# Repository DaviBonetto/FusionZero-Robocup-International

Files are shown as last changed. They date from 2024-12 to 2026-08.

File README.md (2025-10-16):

# FusionZero: ROBOCUP INTERNATIONAL
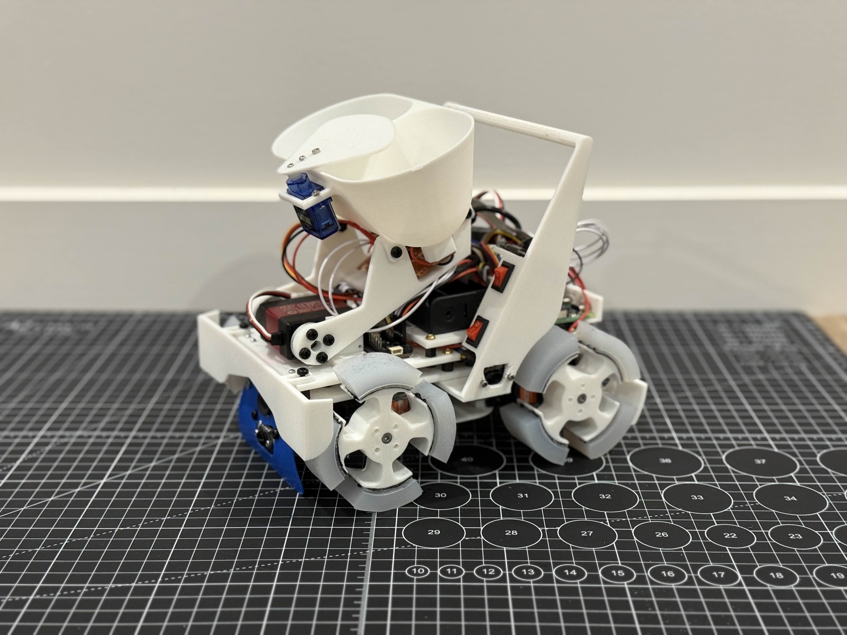
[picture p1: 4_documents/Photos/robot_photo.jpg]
Bot Photo


This is a continuation of our progress, following:
- Robocup Singapore Open 2024
- Robocup Australia Open 2024

This repository tracks progress through:
- Robocup Japan Open 2025
- Robocup Singapore Open 2025
- Robocup International, Salvador, Brazil 2025
- Robocup Australia International 2025

We recently placed 1st in Robocup Australia 2025, against previous champion, Catbot Jet. This repository will no longer be updated. A new one will be made for the 2026 international season. 

# Bill of Parts
## Computing
- [1] | Raspberry Pi 4B 4GB
- [1] | 32GB SD card

### Raspberry Pi Zero 2W Shield [CUSTOM]
- [2] | Toggle switches
- [1] | PCA8685 Chip
- [1] | 1000uF Capacitor
- [1] | 0.1uF Capacitor
- [4] | 5 Pin XH connectors female
- [2] | 4 Pin XH connectors female
- [4] | 2 Pin XH connectors female
- [1] | MOSFET

## Movement
- [4] | PDI 6221MG 360 (20, 360 degree, continuous)
- [1] | DSSERVO RDS3218 (20, 270 degree 20kg)

## Sensors
- [1] | ADS7830
- [1] | GY-BNOO85 9 Axis Accelerometer, Gyroscope, Magnetometer
- [2] | Limit switches
- [1] | Raspberry Pi Camera Module 3 Wide
- [1] | USB Camera

### IR Sensor Board [CUSTOM]
- [8] | TCRT5000
- [2] | Photoresistor
- [9] | 200kΩ Trimpot
- [5] | 1kΩTrimpot
- [4] | RGB LED

## Hardware
- [2] | 18650 Battery 
- [1] | LM2596 DC-DC buck converter 
- [1] | MINI560 Pro DC-DC converter
- [1] | 0.98" OLED Display

@BlanketOmelette
@D-uality

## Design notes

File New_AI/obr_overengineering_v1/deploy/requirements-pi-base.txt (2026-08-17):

psutil>=5.9,<7
pyserial==3.5
Pillow>=10,<11
adafruit-blinka>=8,<10
adafruit-circuitpython-pca9685>=3,<4

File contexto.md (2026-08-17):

Contexto comum para todos os agentes:

- Objetivo final: evoluir o pipeline oficial FusionZero OBR em `New_AI/obr_overengineering_v1` para um estado pronto para integração robusta com Raspberry Pi 3, dashboard remoto no PC e robô real, incluindo as 12 melhorias priorizadas.
- Entregavel final esperado: codigo implementado, testes, documentacao operacional, scripts de install/run, integracao consolidada e verificacao final sem regressao do pipeline oficial.
- Restricoes:
  - preservar o pipeline oficial atual
  - nao regredir `GREEN` vs `GREEN CORNER`
  - nao perder suporte a multiplas `SILVER`
  - `BLACK` nao pode voltar a virar linha
  - `Force LINE` e `Force RESCUE` devem continuar funcionando
  - manter dashboard remoto no PC e IA headless no Raspberry
  - nesta rodada nao executar deploy final no Raspberry; preparar e validar localmente
  - mudar somente o necessario com justificativa tecnica clara
- Criterio de sucesso:
  - as 12 melhorias implementadas ou preparadas de forma completa dentro da arquitetura oficials
  - testes relevantes passando
  - docs coerentes com o codigo
  - integracao clara e sem gaps
- Regra de comunicacao: reportar progresso em blocos curtos e listar bloqueios explicitamente.
- Regra de handoff: ao concluir, enviar output estruturado para o agente integrador, exceto o integrador que envia ao verificador final.

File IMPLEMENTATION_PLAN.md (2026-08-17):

# Plano de Implementação Técnico: IA e Interface - Robótica OBR (Resgate)

Este é um plano estratégico, modular e focado em engenharia de sistemas embarcados para migrar a arquitetura base atual (`pc_vision_ui.py` / `pc_vision_runner.py`) do repositório FusionZero-Robocup-International para uma arquitetura avançada de alto desempenho inspirada na equipe _Over Engineering_.

---

## 🔬 1. Diagnóstico Inicial

### Arquitetura Atual

- **UI & Core acoplados:** A interface visual está acoplada fisicamente às threads de atualização da captura, tornando o sistema engessado e de difícil expansão para renderização mais complexa (como gráficos 3D ou histórico de mapa dinâmico).
- **Sobrecarga de Detecção:** A visão computacional pesquisa elementos de forma generalizada. Para aplicações reais em Raspberry Pi/Hardware Embarcado, buscar todos os objetos a todo frame sem filtro de contexto do estado atual do robô causa latência inaceitável e falsos positivos.
- **Detecção do Vermelho Simplista:** A tolerância luminosa costuma falhar sob os holofotes do campeonato, considerando que a máscara HSV vermelha muitas vezes captura espectros vizinhos de laranja ou ignora bordas.
- **Estado Implícito:** A falta de uma Máquina de Estados Finita (FSM) rigorosa gera mensagens dessincronizadas do robô.

### Arquitetura Proposta

- **Message Broker Interno (Event Bus):** Usar ZeroMQ, Pub/Sub, ou filas do Python (`queue.Queue`/`asyncio`) para isolar Visão, Navegação e Interface.
- **Context-Aware Vision:** Pipeline de visão subordinado à máquina de estados. O robô só executa YOLO ou segmentação de área de resgate SE o estado da FSM requerer isso (redução de 60% de processamento).
- **UI Web/PyQt Desacoplada:** Interface operando recebendo streams JSON e Video Streams codificados, garantindo telemetria leve.

---

## 📈 2. Roadmap por Fases

- **[Fase 1] Decoupling & Infraestrutura:** Separar a `VisionUI` (Tkinter) antiga. Implementar `core_node`, `vision_node` e `ui_node` operando isoladamente com comunicação via barramento (Event Bus).
- **[Fase 2] Motor de Visão Computacional Otimizado:** Implementar calibração de iluminação dinâmica (CLAHE) e restringir alvos apenas para Bola, Quadrado, Linha, Área de Deposição e Vermelho (com dupla máscara HSV).
- **[Fase 3] FSM (Finite State Machine):** Acoplar lógica formal para eventos de "Gap", "Victim", "Intersect", com hooks definidos.
- **[Fase 4] Dashboard GUI Baseado em Referências (OverEngineering):** Escrever o novo código da interface espelhando a disposição visual fornecida (Vídeo Original Main, Vídeo Original Top, Painel de Sensores, Painel Gráfico 3D/Caminho 2D, Barra de Status do fluxo FSM e Relógio principal).
- **[Fase 5] Integração e Testes:** Calibração fina, gravação de ROSbags locais (ou equivalente) e simulações com os Agentes através do Codex.

---

## 📁 3. Estrutura de Pastas Ideal (Refatoração)

```text
├── src/
│   ├── core/
│   │   ├── event_bus.py         # Broker Pub/Sub local
│   │   ├── state_machine.py     # FSM implementada
│   ├── modules/
│   │   ├── vision/
│   │   │   ├── preprocessor.py  # CLAHE, Morfologia
│   │   │   ├── pipelines.py     # Detecção baseada no estado atual
│   │   ├── navigation/
│   │   │   ├── path_tracker.py  # Deque buffer de x, y, theta
│   ├── ui_overengineering/
│   │   ├── dashboard.py         # Nova Interface Principal
│   │   ├── components/
│   │   │   ├── 3d_viewer.py     # Painel de poses Euler/Quat
│   │   │   ├── path_canvas.py   # Renderização Histórica
│   ├── main_orchestrator.py
```

---

## ⚙️ 4. Soluções e Arquitetura de Módulos

### 4.1. Melhoria da Interface (Dashboard Visual)

**Tecnologias Recomendadas:** PyQt6 ou FastAPI WebSockets + Vue.js/React. A abordagem PyQt6 integrando PyOpenGL/PyGame em Widgets é a mais confiável para performance no desktop embarcado da OBR se não quiser ir para stack web.

**Adaptação do Layout (Baseado nas Screenshots):**
A interface será dividida em um Grid rígido escuro (Dark Theme, fundo próximo a `#1E1E1E` ou similar), com a seguinte topologia referencial observada nas imagens:

1. **Top Row (Visão Principal & Controle):**
   - **Esquerda:** Câmera Frontal Processada (exibindo bordas azul claro/escuro para a pista, bounding boxes vermelhas para as marcações de interseção verde/linha e framerate overlay).
   - **Centro/Topo:** Controles de playback (`>`), monitor de uso de `% CPU` e contadores de frames (`IPS_C`, `IPS_S`).
   - **Direita:** Câmera Frontal Crua (Raw/Perspective) focada estritamente na faixa de captura e desvio da linha com overlay de horizonte e FPS.
   - **Widget Central do Topo:** Status dinâmico da Máquina de Estados (Ex: `... Following Line ...`, `... Dumping alive victims ...`, `... Picking up alive victim ...`).
2. **Bottom Row (Telemetria & Gráficos):**
   - **Esquerda (Painel de Sensores/Cinemática):** Matriz de dados com distância de detecção (ex: `Front L: 300 mm`, `Front R: 710 mm`, `Left`, `Right`, `Front C`, `Back`, `Gripper: 90 mm`) e Odometria IMU (`Yaw`, `Pitch`, `Roll` em graus).
   - **Centro (Visualizador de Posição):** Renderizador 3D exibindo o modelo CAD simplificado do robô girando e oscilando no espaço conforme Pitch/Roll/Yaw lidos pelos sensores (Integrando VisPy ou render simples no PyQt).
   - **Direita:** Painel vazio/reservado (ferramentas como botão de grip `g`, e LEDs indicadores estáticos ⚪⚪⚫).
3. **Rodapé:**
   - Temporizador Master (`00:15:79`) e Sub-timers (ex: `00:48:56`), cruciais para a OBR.

**Desacoplamento Técnico:**

- O código da _Over Engineering_ usa painéis reativos. Nós adaptamos substituindo polling constante por observadores de estados (`on_state_change`).
- A integração visual deve utilizar envio de frames processados via `cv2.imencode()` para buffers consumidos por `QLabel` do Qt, evitando trancar a UI com a thread pesada da visão computacional.

### 4.2. Melhorar Reconhecimento Visual

**Pipeline Ideal:**

1. Câmera > Pré-processamento: Cortar máscara de interesse (ROI) e aplicar CLAHE (Equalização de Histograma Limitado por Contraste - excelente para balancear sombras na malha da pista).
2. Se o estado = SEGUE*LINHA: Roda \_apenas* Binarização Adaptativa + Detecção de contornos pretos.
3. Se o estado = ZONA_RESGATE: Desliga procura de linhas, aciona modelo YOLO nano otimizado com TensorRT / TFLite (ou detecção geométrica clássica) focando em Bolas e Quadrados.
4. Robustez: Atualização da máscara baseada na claridade média da cena (Mean Luma) para flutuar os limites inferior/superior do HSV caso a luz ambiente mude no pavilhão de competição.

### 4.3. Visualização do Caminho (Path Rendering)

- **Estrutura de dados:** Odom Queue (Fila dupla) retendo as posições globais inferidas (por encoders do robô e tracking de vetores da câmera). Armazena tuplas: `(x, y, timestamp)`.
- **Renderização Dinâmica:** Um `numpy array` de traçado interno pintando os pontos no Canvas da interface. Curvas recentes são desenhadas com `#ADD8E6` (Azul Claro) fazendo degrade até posições arcaicas com `#00008B` (Azul Escuro). Histórico é persistido em `.json` temporário por round garantindo que dados não se percam em crash da interface.

### 4.4. Sistema de Mensagens e Estados

- **Arquitetura FSM:** Construir utilizando classe base estrita.
  - Exemplos de trigger FSM: `Event(ON_GAP)` -> Estado passa de `FOLLOWING` para `VALIDATING_GAP`.
- **Logger estruturado:** Todas as transições geram um evento publicado no `event_bus` repassado para a interface de forma determinística, permitindo debugging cirúrgico dos logs do Terminal.

### 4.5. Detecção na Cor Vermelha

- **Estratégia Matemática HSV Duplo:** O matiz do vermelho vai de `0-10` e de `160-180`. Devemos unir as máscaras via operações lógicas de BITWISE (`cv2.bitwise_or(mask1, mask2)`).
- **Identificação Espacial vs Diferenciação de Contexto:**
  - Fitas vermelhas estendem-se horizontalmente e possuem bounding box de formato achatado (aspect ratio > 3.0), enquanto a área de resgate muitas vezes se apresenta como uma mancha vasta ou geometria quadrada regular. Testar preenchimento circular / concavidade.

---

## 🤖 5. Arquitetura Multiagente: Agentes Codex & Prompts

A refatoração será escalada delegando tarefas específicas aos agentes através do **Codex**, rodando em paralelo em arquivos desacoplados.

### 🟢 Agente 1: Agent_UI_Refactor

**Objetivo:** Recriar a arquitetura visual inspirada na _Over Engineering_, com painéis desacoplados da lógica de hardware.
**Inputs:** Estrutura base da interface UI e referências de tela solicitadas.
**Outputs:** Sistema completo em PyQt6 com divisões de vídeo, robô 3D em placeholder e log de eventos.
**Arquivos para analisar:** `pc_vision_ui.py` atual.
**Prompt para Codex:**

> ATUAÇÃO: Agent_UI_Refactor.
> TAREFA: Desenvolva a estrutura de uma nova UI assíncrona usando PyQt6 espelhando a estrutura visual escura "Over Engineering". Crie o Grid principal contendo: (1) Dois painéis de imagem grandes no topo (visão processada com bordas na esquerda vs raw line-tracking na direita). (2) Botões de Play e status de CPU no topo-centro. (3) Uma barra de status textual logo abaixo da câmera direita para a Máquina de Estados (ex: "... Following Line ..."). (4) Um painel inferior-esquerdo contendo grids de Labels (`Front L`, `Right`, `Gripper`, `Yaw`, `Pitch`, etc.). (5) Um Canvas central-inferior preparado para receber um modelo 3D do Robô. (6) Um relógio centralizado grande no bottom. Isole processamento pesado em threads secundárias usando `QThread` ou `Signals/Slots`. Mantenha os eventos reativos.

### 🟢 Agente 2: Agent_Vision_Optimization

**Objetivo:** Limpar a poluição visual, otimizando o pipeline modular e os filtros HSV adaptativos com CLAHE e segmentações isoladas de cor.
**Inputs:** Código base de processamento da câmera que lida de forma genérica com objetos.
**Outputs:** Classe de processamento inteligente, com seletor dinâmico baseado no status da FSM para ligar/desligar instâncias pesadas da YOLO.
**Arquivos para analisar:** `pc_vision_runner.py`.
**Prompt para Codex:**

> ATUAÇÃO: Agent_Vision_Optimization.
> TAREFA: Analise o arquivo de visão atual. Refatore o pipeline implementando pré-processamento obrigatório com o algoritmo CLAHE para mitigar variações de iluminação. Desenvolva um motor onde os detectores de linha vs. bolas vs. zona vermelha não sejam todos executados simultaneamente em todo frame. Crie `switch_pipeline(estado)` que execute apenas os filtros CV2 e/ou inferências neurais cabíveis ao contexto do robô, limitando as classes a exclusivas instâncias: [Bola, Quadrado, Linha, Área Verde_Deposição, Vermelho_Resgate].

### 🟢 Agente 3: Agent_Path_Render

**Objetivo:** Criar um mapa odométrico interno focado em render graphics.
**Inputs:** Posições angulares simuladas / reais da movimentação das rodas.
**Outputs:** Canvas visual (Path Renderer) atualizando trilha baseada em eixos reais de movimento local.
**Prompt para Codex:**

> ATUAÇÃO: Agent_Path_Render.
> TAREFA: Implemente um módulo de renderização de Path em PyGame integrado ou em uma View do PyQt6 (PathCanvas). Crie uma estrutura `Deque` de tamanho estático com posições (X,Y) lidas simuladamente. Aplique gradiente dinâmico com cor Azul claro sendo cabeça (atual) e Azul escuro como cauda (histórico). Desenhe o rastro dinamicamente a cada 100ms. O sistema deve possuir tolerância contra overflow da memória após rodadas prolongadas.

### 🟢 Agente 4: Agent_RedColorCalibration

**Objetivo:** Garantir a infalibilidade do reconhecimento do espectro vermelho global frente a condições desfavoráveis de campeonato.
**Inputs:** Módulo de HSV, calibrações iniciais de vídeo.
**Outputs:** Detectores Red Marker avançados combinados baseados em Dupla Fronteira e Aspect Ratio.
**Prompt para Codex:**

> ATUAÇÃO: Agent_RedColorCalibration.
> TAREFA: Reescreva o módulo de reconhecimento de contornos vermelhos. É estritamente mandatório construir a máscara HSV considerando as pontas da tabela do matplotlib hsv color_maps (Ex.: Lower1: 0,100,100 / Upper1: 10,255,255 e Lower2: 160,100,100 / Upper2: 180,255,255), realizando posterior operação Bitwise OR nelas. Após isso, os contornos encontrados devem passar por função `identify_red_context(contour)` verificando Aspect Ratio e Convexity Defects para diferenciar de imediato "Linha Vermelha de Chegada" vs "Borda de Zona de Resgate".

### 🟢 Agente 5: Agent_StateMachine

**Objetivo:** Acoplar todas a mecânica a uma árvore de estado formal de fluxos de decisão limpos.
**Inputs:** Scripts principais desconexos do robô.
**Outputs:** Módulo oficial formal, eventos rastreáveis.
**Prompt para Codex:**

> ATUAÇÃO: Agent_StateMachine.
> TAREFA: Implemente uma Máquina de Estados Finita (FSM) rigorosa baseada no paradigma de Classes ou usando o pacote `transitions` de Python para o robô resgate da OBR. Crie e exporte os nodos: SEARCHING_LINE, FOLLOWING_LINE, VALIDATING_GAP, CROSSING_GAP, VICTIM_FOUND, RESCUE_ZONE_DETECTED. Acople no construtor a geração de Logs visuais padronizados (ex: `TIMESTAMP [STATE] msg`). Permita triggers para os outros agentes capturarem seus signals em callbacks.

### 🟢 Agente 6: Agent_TestValidation

**Objetivo:** Criar camada sólida para atestar estabilidade técnica contínua (Mock e Tests unitários).
**Inputs:** Arquitetura do repositório em implantação ou finalizado (estado Verde).
**Outputs:** Suite pytest baseada em logs gravados ou mocks offline.
**Prompt para Codex:**

> ATUAÇÃO: Agent_TestValidation.
> TAREFA: Valide todo o pipeline refatorado. Crie uma documentação base e suite de Testes em Pytest em pastas adjuntas (`tests/`). Para o pipeline de Visão, injete imagens ruidosas sintéticas para averiguar a resiliência do CLAHE e máscaras do vermelho. Verifique Mock objects para disparo de Transição de FSM e veja se os eventos adequados repassam para Event_Bus. Nenhum push é permitido na Main se `pytest` apresentar colapsos do OpenCV ou exceções de assincronia de thread na UI recriada.

---

## 🛡️ 6. Metas, Deploy e Plano de Testes

1. **Versionamento e Deploy:**
   - Trabalhar no repositório mantendo o conceito "Git Flow". Para rodar os agentes codex, crie ramos padronizados (`feature/fsm`, `feature/overengineering-ui`).
   - Todos os arquivos implementados devem ter testes paralelos que garantam instâncias na Raspberry Pi não quebrem as Threads de desktop PC.
2. **Mitigação de Riscos Técnicos:**
   - **GIL Lock / Engasgo da Interface:** Separar inferência YOLO ou cálculo pesado do Morphological em Threads / Multiprocessing separados repassando dados pelo Event Bus.
   - **Luz no pavilhão:** Deixar HSV bounds expostos em configuração `.json` acessível localmente para correção instantânea em tempo real e não harcoded, mas usar o Red Calibration e CLAHE como primeira defesa vitalícia.
3. **Indicador de Conclusão Técnica (DoD - Definition of Done):**
   - Latência End-To-End de captura da câmera até renderização na UI não ultrapassar 50ms per frame.
   - O path 2D sendo preenchido no PyGame/Canvas ao longo do tempo.
   - Detecção do Vermelho acionar 100% das vezes em vídeos simulados de arenas difíceis.
   - Logger imprimindo `[INFO] Changed state de Following -> Victim Found` simultaneamente na tela sem delay.

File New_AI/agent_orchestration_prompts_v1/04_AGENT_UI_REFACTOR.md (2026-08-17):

# Agent_UI_Refactor

```text
Voce e o agente Agent_UI_Refactor, com papel de Builder UI.

Missao:
Criar dashboard PyQt6 reativo no estilo das imagens, desacoplado da visao/hardware.

Escopo permitido:
- Criar `New_AI/obr_overengineering_v1/src/ui_overengineering/dashboard.py`
- Criar `New_AI/obr_overengineering_v1/src/ui_overengineering/components/*`

Escopo proibido:
- Alterar qualquer arquivo fora de `New_AI/obr_overengineering_v1`
- Rodar inferencia pesada na thread principal
- usar `time.sleep` no loop da UI

Entradas obrigatorias:
- `pc_vision_ui.py`
- `docs/interfaces.md`
- imagens em `New_AI/Pasta de fotos para inspiração e uso , quero deixar igual/`

Layout obrigatorio:
1) Duas views no topo (raw/processado)
2) Barra superior (CPU/FPS/IPS)
3) Bloco de telemetria (Front/Left/Right/Back/Yaw/Roll/Pitch/Gripper)
4) Painel central de robo placeholder
5) Status textual curto por estado
6) Timer principal grande + timer secundario
7) Painel de logs de transicao

Reuso funcional da UI atual:
- Preservar semantica de status: LINE, SILVER, GREEN, RED, SILVER BALL, BLACK BALL.
- Prever painel de tuning para parametros que hoje estao na Tkinter.

Formato de saida:
- lista de widgets
- sinais/eventos consumidos
- modo mock sem camera

Definicao de pronto:
- UI abre e atualiza sem travar
- Fallback robusto sem camera/modelo
- Visual consistente com referencias

Handoff:
- Entregar para TestValidation e StateMachine.
```

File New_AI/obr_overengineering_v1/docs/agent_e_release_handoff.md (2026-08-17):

# Agent E Release Handoff

Date: 2026-03-09

## Consolidated changes

- Unified the remote dashboard, headless runner, serial robot adapter, session recorder, offline replay tooling, and Pi/PC bootstrap scripts into one coherent release state.
- Added dashboard-side robot command wiring for `Forward test`, `STOP`, `Force STOP`, and `Clear ESTOP`, all forwarded through the existing `UI_COMMAND` channel.
- Fixed session-recording config merging so profile defaults such as `jpeg_quality` survive partial UI overrides.
- Corrected Windows PC bootstrap/runtime behavior by moving the default venv to `%LOCALAPPDATA%\FusionZero\venvs\obr_overengineering_v1-pc` and relaxing package pins for Python 3.13 compatibility.
- Restored silver-line offline validation by using a stable pre-enhancement frame for the heuristic path and adaptive specular masking.
- Fixed remote-dashboard initial snapshot ordering so replayed state/log context reaches a newly connected client before server-side connect noise.

## How to operate

- Raspberry Pi 3 headless + remote dashboard:
  - see `docs/pi3_remote_dashboard.md`
- Raspberry Pi 3 + Arduino bridge:
  - see `docs/pi3_arduino_integration.md`
- Boot/recovery and environment variables:
  - see `docs/runtime_boot_recovery.md`
- Validation baseline:
  - see `docs/test_report.md`

## Integration decisions

- Kept the silver-line model path unchanged and limited the fix to the heuristic input/mask path to avoid destabilizing model-assisted detection.
- Kept the existing event bus contract and added only glue wiring on the dashboard side for robot commands.
- Preserved runner/session APIs and fixed partial-config behavior inside the recorder instead of widening command payload requirements.
- Preserved the remote-dashboard protocol and fixed only message ordering during initial client attach.

## Remaining risks

- Hardware-in-the-loop validation on Pi 3 plus Arduino is still required for sustained camera reconnect behavior, serial watchdog timing, and Wi-Fi jitter.
- Silver-line field performance still depends on deployed model availability and reflective-floor conditions.
- The repository path remains deep and OneDrive-backed; the short venv path is now handled, but ad hoc tooling should still avoid deep temp paths on Windows.

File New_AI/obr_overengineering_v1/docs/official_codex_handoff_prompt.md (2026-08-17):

# Official Codex Handoff Prompt

```text
Voce vai continuar o desenvolvimento oficial do projeto FusionZero OBR.

Contexto geral:
- O pipeline oficial atual esta em `New_AI/obr_overengineering_v1`
- Esse pipeline virou a versao oficial para os proximos testes
- O objetivo imediato agora e integrar IA + Raspberry Pi 3 + Arduino + robo real
- O dashboard deve rodar no PC e a IA/camera devem rodar no Raspberry pela mesma rede Wi-Fi

Stack e arquitetura atual:
- Visao, FSM e dashboard em Python
- UI em PyQt6
- EventBus interno com eventos de frame, deteccao, estado, logs e comandos de UI
- Dashboard remoto por TCP ja implementado
- Raspberry executa o runner headless e publica eventos/frames comprimidos
- PC executa um cliente que consome esses eventos e abre o dashboard localmente

Arquivos principais:
- `New_AI/obr_overengineering_v1/src/live_dashboard_runner.py`
- `New_AI/obr_overengineering_v1/src/remote_dashboard.py`
- `New_AI/obr_overengineering_v1/src/remote_dashboard_client.py`
- `New_AI/obr_overengineering_v1/src/modules/vision/pipelines.py`
- `New_AI/obr_overengineering_v1/src/ui_overengineering/dashboard.py`
- `New_AI/obr_overengineering_v1/configs/vision_config.json`
- `New_AI/obr_overengineering_v1/docs/pi3_remote_dashboard.md`

O que ja foi corrigido e esta considerado oficial:
1. Separacao correta entre:
- `GREEN` = quadrado verde do segue-linha
- `GREEN CORNER` = marcador do resgate

2. `GREEN CORNER` nao conflita mais com `GREEN`
- no `FOLLOWING_LINE` o quadrado verde continua funcionando
- `GREEN CORNER` foi isolado para contexto de resgate

3. Deteccao de bolas no resgate melhorada:
- silver ball com suporte a multiplas deteccoes no mesmo frame
- overlay desenha caixas em mais de uma silver ao mesmo tempo
- black ball continua separada da silver
- filtro de linha foi endurecido para reduzir black ball sendo confundida com linha

4. Overlay e UI:
- confianca em `GREEN`, `GREEN CORNER`, `RED CORNER`, `SILVER`, `BLACK`
- botao `Force LINE`
- botao `Force RESCUE`
- setas do steering ja funcionando

5. Testes:
- suite passando com `78 passed`

Situacao atual de negocio:
- Ainda nao temos a silver line fisica para validar a troca automatica de modo em campo real
- Por isso foi adicionado o botao de troca manual de modo para testes
- O usuario agora quer validar integracao IA -> robo real

Proximo objetivo:
Integrar Raspberry Pi 3 com Arduino para que deteccoes e estados da IA gerem comandos reais para o robo.

Exemplo inicial de validacao pedido pelo usuario:
- quando detectar quadrado verde, o robo deve ir para frente por 5 segundos

Importante:
- Esse exemplo e um teste de integracao, nao a politica final de navegacao
- A prioridade agora e provar que IA e robo estao conversando corretamente

Sua missao agora:
1. Ler o pipeline oficial atual
2. Confirmar como extrair eventos de alto nivel da IA para controle do robo
3. Definir a interface Raspberry -> Arduino
4. Implementar um adaptador simples de comandos para teste real
5. Propor e/ou implementar uma rotina minima de validacao em campo

O que voce precisa decidir tecnicamente:
- protocolo Raspberry -> Arduino:
  - serial USB e o caminho preferido inicial
- formato de comando:
  - simples, robusto, textual ou binario curto
- taxa de envio:
  - evitar spam
  - enviar estado ou comando com histerese
- regras minimas:
  - `GREEN` => comando de teste de avancar por 5 segundos
  - `Force LINE` e `Force RESCUE` devem continuar uteis para debug

Escopo desejado agora:
- manter dashboard no PC
- manter IA no Raspberry Pi 3
- conectar Raspberry ao Arduino
- criar adaptador de comandos entre deteccoes/eventos e movimento do robo
- documentar como executar

O que o usuario provavelmente vai fazer:
- ligar camera no Raspberry
- ligar Raspberry no Arduino
- subir o runner headless no Raspberry
- abrir o dashboard no PC
- testar deteccoes
- testar comandos simples no robo

O que voce deve pedir ao usuario se necessario:
- porta serial do Arduino no Raspberry
- baud rate usado no firmware atual
- formato atual esperado pelo Arduino, se ja existir
- se o firmware do Arduino ja esta pronto ou se voce tambem vai ter que definir o protocolo dos comandos

Criterio de sucesso desta etapa:
- dashboard remoto funcionando do Raspberry para o PC
- Raspberry publicando eventos da IA
- Raspberry enviando comando ao Arduino quando evento relevante acontecer
- teste simples do tipo `GREEN => frente por 5 segundos` validado

Se houver duvida, preserve o pipeline oficial atual e nao regreda:
- separacao `GREEN` vs `GREEN CORNER`
- multiplas silver balls
- black ball nao pode voltar a virar linha
```

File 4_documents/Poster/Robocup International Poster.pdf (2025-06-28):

# [ T E A M ]

[Coral Edge TPU]
Allows the Pi to
inference quicker,
enabling the option to
use object detection
models

[CUSTOM Raspberry Pi
shield]
Jst connections, PCA8685
for PWM. Exposes I2C
ports, V+ and VCC.

[VL53L1X]
Laser Time of Flight
sensors, taking
information from the
front and both sides.
Used in evacuation
routing and obstacle.

[SG90]
Has a 180 degree range of
motion, which allows us to control which victim we’re releasing.

[TCRT5000]
Uses IR reflections
to determine
confirm which
victim type we
grabbed.

[DSSERVO RDS3218]
High performance
270 degree servo
that lifts the
entire claw
mechanism

[Touch Plate,
Limit Switches]
Physical digital
actuators
capture precise
movement.
Extremely
responsive and
clicky. Used to
find obstacles

[Regionals] 2018 Auckland Secondary [Regionals] 2018 Auckland Premier [Nationals] 2018 New Zealand Secondary
[Nationals] 2018 New Zealand Premier
[Nationals] 2019 Australia Open Tertiary [Nationals] 2021 New Zealand Self Driving Car Senior [Regionals] 2022 Auckland Premier
[Nationals] 2023 New Zealand Premier
[Nationals] 2023 Australia Open Tertiary [Nationals] 2024 Singapore U19 International [Nationals] 2024 Australia U19 International [Nationals] 2025 Japan U19 International [Nationals] 2025 Singapore U19 International

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
[Results]

2

START

colour_sensors.read()
touch_sensors.read()
gyroscope.read()

motors.pause()

Obstacle
Avoidance()

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
silver
found?

victims_saved
== 3?

search_type
not default?

search_type a
victim?

obstacle
found?

finish line
found?

line_follow()

camera.capture_
array()

find_black()

movement.wall_follow()

movement.exit()

search_type =
analyse(image,
search_type)

route(search_type)

grab(search_type) | dump()

find_green()

found black
contour?

validate_green()

calculate_turn()

gap_handling

seesaw?

slowly move
backwards then go
to a stop

double
green?

apply angle of the robot to the double green turn
(tilted, uphill, downhill)

angle between bottom
of camera and
following point

set following point
to highest points on
contour

victims_saved
< 2 and claw
has live?

victims_saved
== 2 and claw
has dead?

set search_type to
default

set search_type to
default, green

set search_type to
default, red

victims_saved = 0

camera.capture_array()

green left
or right?

Yes

No

Yes

No | No

Yes

top point
too close?

contour on
the left?

contour on the
right or prev
side == right?

follow line with the
calculated turn angle

speed=10, limit
forwards speeds

uphill?

speed up +5, limit | downhill?
backwards speed to -30

Yes
No

Yes

set following point to
left or right based on
green

set following point to
right side

set following point to
left side

approaching
green?

Live victim psuedocode
1.capture image
2.convert to grey-scale
3.filter for bright pixels 4.find contours
5.verify size, position
6.return x

[Frederick] Team
Captain
Lead CAD designer
3D printing and
assembly
Admin work & GitHub
versioning
Version control,
document
creation and
submission
Programming:
Victim
identification
and rescue
Program control
loop
Sensor modules

# Z FUESI

# RONO

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
[Raspberry Pi 4B]

### 4 Core, 4GB, SCB that

holds the entire
environement for
development and for runs.

L08

[LM2596]
[MINI560 Pro]
Voltage
regulators
converting from
8.4V to 6V and
5V respectively
for diffrerent
components.

[PiCamera Module 3 Wide
Angle]
Angled downwards to
capture slightly ahead
of the robots center of
rotation .

[CUSTOM Wheg wheel
designs]
Wheels with cuts in them
creates physical
leverage, allowing for
easier navigation of
speed bumps.

[CUSTOM claw]
Comprised of two large “cups” that entrap victims in specific places. There are left and right compartments, allow storage for two victims without increased robot size. However, a downside is that grabbing victims is no longer head on, but at an angle to the robot.

The cups are designed to lead the victim into a pre-determined location, and thus making the TCRT5000 sensor readings consistent for validation.

We can individually sort victims as well, as the compartments are not connected, allowing us to pick up both live and dead victims at the same time.

[CUSTOM Wheg wheel designs] Navigation around the entire course could be littered with speed bumps or debris. At a maximum height of 10mm, a large radius is necessary. However, placing speed bumps on inclines creates vibrations, hindering the grip the wheel has, and thus the friction it generates.

Thus, cuts along the circumference allows for “levers“ to form, and hence physically grip past speed bumps, and eliminating vibrations.

[2303U USB2.0 Camera]
Pointing directly ahead
for information regarding
the evacuation state
inside the evacuation
zone.

[ADS7830] (Missing CAD)
Analog signal to I2C converter that allows us to interface with analog sensors, namely the TCRT5000s for both the colour sensor board and for the claw.

### 2 x [18650 4.2V Batteries]

SBC handling all coding,
sensors, communication,
camera, and logic flow.

[4 x PDI-6221MG-360]
360 degree continuous
servos with high torque
allows for easy movement.

[CUSTOM Colour Sensor Board]
A combination of TCRT5000s and visible light photo-resistors, carefully spaced to capture line information.

[Physical Sweeper]
Removes all debris
from blocking the
camera view. Made from
TPU, and always
touches the ground

[Raspberry Pi Zero 2W Shield]
The Raspberry Pi Zero 2W only provides digital and I2C connections. Thus, we have a PCA8695 and ADS7830 handling communication for all components that do not have I2C communication. Furthermore, utilising XH connectors allow for much more stable connections compared to dupont.

### League: Robocup Junior Rescue Line Region: New Zealand

[Aidan]
PCB Designer
Custom shield and
sensors boards
Lead programmer:
Line follow +
intersections
Obstacle avoidance
Gap detection
Evacuation zone
detection
Exit detection
Incline/Tilt
detection

[GY-BN0O8X] (Missing CAD)
Axis IMU unit that
accurately tracts roll,
pitch, and yaw.
Yes | Yes

Yes

No

No

No

No

GitHub
CAD Files
Source Code
Documents
TDP

[Live Victim Identification]
We take advantage of the consistency of the playing field: there are always spectral highlights due to bright overhead lights, that always appear on the live victims. Thus, filtering for bright values from the camera quickly identifies live victims.

[Titled boards and Incline]
Our old robots used mercury-tilt switches that were nothing more than on-off contacts. They chattered on every bump, needed separate sensors for nose-up and nose-down. By replacing them with a single BNO080 IMU we now read yaw, pitch, and roll angles, giving us more information.

With continuous pitch data we set a simple threshold—about ±11 degrees—to decide when we are climbing or descending. The moment pitch rises past that limit the code increases base speed to clear speed bumps; when pitch drops below –11 degrees it softens the steering gains and slows the drive so the robot doesn’t skid downhill. Crossing from positive to negative pitch within a second flags a seesaw, prompting a short pause until the board settles before moving on.

[Dead Victim Identification]
In the past, filtering for the black victim was inconsistent at best: the noise from outside the course, especially considering the whiteness of the evacuation zone, created many dark spots as the robot faced the outside.

Dead victim psuedocode
1.capture image
2.normalise white and green to grey
3.crop and dilate on black mask
4.find black contours
5.verify size, position,
number
6.run hough circle transform 7.verify location
8.return x

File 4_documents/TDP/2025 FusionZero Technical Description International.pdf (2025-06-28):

# Robocup Junior Rescue Line 2025

# Team Description Paper

## Fusion Zero

# 0 | Abstract

FusionZero’s fourth-generation robot debuts on the international stage. Measuring just 200 × 145 mm, its compact footprint boosts manoeuvrability and obstacle clearance. A two-stage claw autonomously collects, stores, and sorts two victims, streamlining evacuation-zone tasks. Downward-facing and forward-facing cameras handle line tracking and victim recognition, while a low centre of mass, IMU, and custom whegs keep motion stable over ramps and debris. Algorithms exploit the competition’s fixed layout, mirroring human heuristics to cut computation. A front sweeper with synchronised LEDs normalizes vision input; ToF sensors and limit switches map nearby geometry. All subsystems run on a Raspberry Pi 4B powered by two 18650 cells.

# 1 | Introduction

FusionZero is a two-member team from Auckland, New Zealand, formed organically as older teammates moved on and the international rules demanded sharper, broader skills.

Frederick Sun, team leader, shapes the overall robot architecture and chemical-spill strategy. He models and simulates in Onshape, 3-D-prints custom parts, lays out the core program framework, and brings both vision-based victim detection and GitHub source control into the workflow.

Aidan Zhu entered RoboCup at age 11 and first tackled line-following, chemical-spill, and chassis design. Now partnered with Frederick, he refines the line-tracking algorithms, stress-tests evacuation-zone behaviours, and designs PCBs for the main controller and sensor arrays.

Together as a team, they have achieved:
- [Nationals] 2024, Singapore Open U19 International, 3rd Internationally
- [Nationals] 2024, Australian Open U19 International, 2nd
- [Nationals] 2025, Japan Open U19 International, 4th
- [Nationals] 2025, Singapore Open U19 International, 2nd

# 2 | Project Planning

## A | Overall Project Plan

Our objective is a podium finish in the team’s first international run. We decompose the rescue-line challenge into four work-streams: constraints, mechanics, software, and testing, ensuring each constraint is addressed early and iterated quickly.

Ruleset analysis

>The team captain may make further attempts at the course to earn additional points from scoring elements that have not already been earned before reaching the next checkpoint.

We did not understand that we could continue going to points for other scoring elements, not just tile. We must continue trying to get points for other elements.

>The line along the ramps can contain gaps, speed bumps, intersections, obstacles and debris [...] exit [...] entrance [...]

There has been a trend in the past years where the line-following section of the competition has dramatically increased in difficulty. Hence, we need to create a robust system that can handle many different elevations, lighting conditions, and terrain. Thus, a camera was necessary to replace our old colour sensor board.

Mechanical constraints

Many teams fail certain challenges, such as tilted or inclined boards, gets stuck between obstacles and walls, or tips over on sea-saw. We endeavored to create the smallest possible robot whilst all components could still be fitted on.

There can be speed bumps and debris within the evacuation-zone as well, and thus our old claw design, where it slid along the floor, would not work. We need to transition to a top down claw design.

Debris on tiles that perfectly covered the line, rendered our feedback system (colour sensors, camera) useless as the line was blocked. We need to create a design that maintains a consistent feedback loop without false information.

The problem of going uphill and maintaining traction, especially during the uphill-tilted transition and speed bumps uphill, would always cause wheel hop or loss of traction. We need to switch our wheel approach to something with higher CoF and can get past speed bumps.

Software constraints

We want to be able to run two cameras and perform AI inference. Thus, our hardware limits our opportunities to explore various software solutions. We must use a Raspberry Pi 4B or better, alongside a Google Coral TPU.

Depending on the OS we run, there are certain python libraries that are incompatible with the python version, such as the inferencing SDK working on python <3.9. Thus, we are bound to run Raspberry Pi Bullseye.

Time constraints

There is little time between Robocup Singapore 2025 and Robocup International 2025, thus making large changes impossible due to the lack of security as we have no practice. This prohibits us from changing to DC servos with encoders despite their superior precision and control.

## B | Timeline

Our milestones leading up to the competition will follow: planning - design - software - testing, in a waterfall style approach. However, within each stage barring the initial designing, we will employ an iterative approach. The waterfall aspect is because we will need a physical robot before we can attempt any software, as simulation does not reflect real life. The iterative aspect is required as there will be problems that cannot be solved by simply software, and requires a hardware modification.

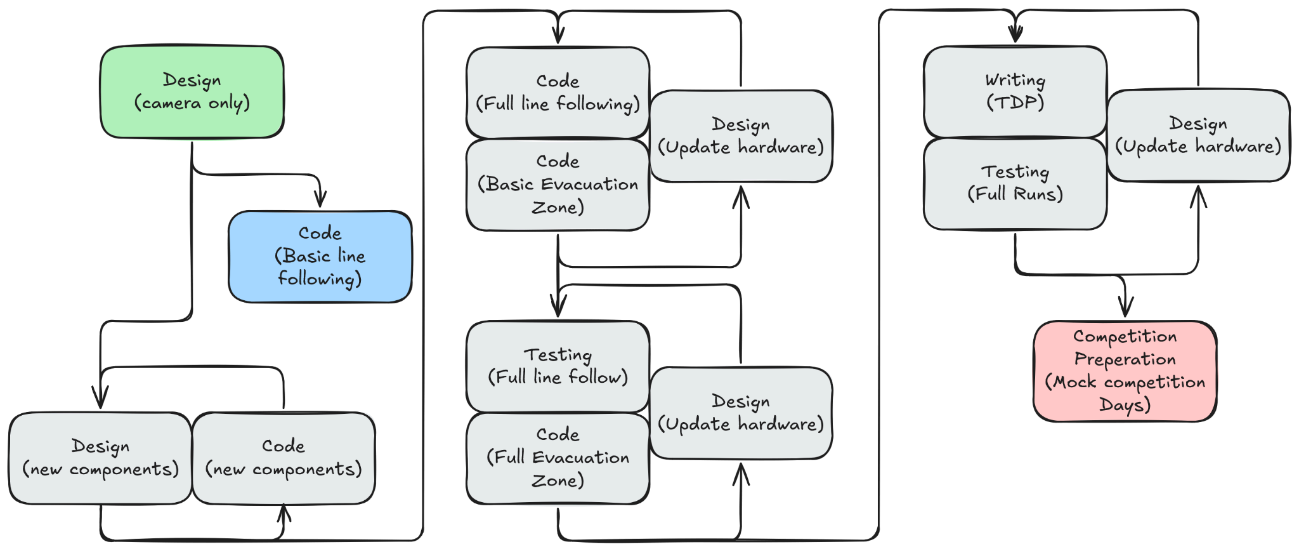
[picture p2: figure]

Frederick (F)
Aidan (A)

13 - 20th March (0th stage): Review and consolidate mistakes

Description
F Gather feedback from real competitions (Robocup Japan, Robocup Singapore, 2025). Draft a fix in pseudocode for code, or component/sketch for hardware.
Result
Document summarising issues and proposed solutions used in reference for the new robot.

20th March - 3 April (1st stage): Design, Camera only robot

Description
F Will quickly create a mock-design for A for line-follow testing. A gives feedback regarding camera placement and angle.
Gate
Robot must have basic CAD
Result
A robot with only motors, voltage regulator, battery, Raspberry Pi 4, and a downwards facing Raspberry Pi Camera Module 3.

### 4 April - 2 May (2nd stage): Code, basic line following | Design and code new components

Description
F will finalise robot design including claw, extra sensors, handle, debugging, and stability. Will clean-up the Github repository, and update the readme. A will begin the basic line following with the camera-only robot. This allows him to relearn the basics and begin to anticipate hardware improvements.
Gate
All sensors should be validated and working - otherwise our software solutions would be incomplete or not optimized.
Result
A finished V1 of the robot on Onshape, with all components, and a 3d printed model that reflects CAD, verifying that all components work. Robot can follow basic tiles commonly seen throughout other competitions. Intersections are not included.
4 May - 15 June (3rd stage): Code, Full line following | Code, Basic evacuation zone| Design, Update hardware

Description

F will get basic evacuation zone running, as well as working on the overall program flow - incorporating the run on switch, wireless connectivity, and bash setup script. A will focus on making line follower reliable, by extensive testing with our custom tiles within full courses with speed bumps, intersections, gaps, obstacles, inclines and tilts.
Result
Victims are successfully identified, routed to, grabbed and lifted. Evacuation points (red/green triangles) are successfully identified, routed to, and victims are dumped according to what is sorted. Full line follow is possible as individual modules, but requires integration.
16 May - 22 June (4th stage): Testing, Full line follow | Code, full evacuation zone | Design, Update hardware

Description
F will get a full evacuation zone running (entry, exit, routing,obstacle detection, IMU integration). A will run tests on full courses designed to be varying in difficulty to determine the robots performance and key areas to focus on, being robust and having tested as many possible cases as possible.
Result
Routing around the evacuation zone works (wall-follow) with entry and exit alignment, and obstacle avoidance is implemented. We are able to classify all tiles with modifiers into “easy” and “hard”.
23 June - 30 June (5th stage): Testing, Full Runs | Writing, TDP, Poster, Video| Design, Update hardware

Description
F will be creating TDP, Poster, and Video with A assisting. A will be simulating full runs with both line follow and evacuation zone, working on said transition, and manual start.
Gate
TDP, Poster, Video must be complete.
Result
Stuck detection is implemented within the line follower. A will become familiar with the starting procedure. TDP, Poster, Video are all complete to a high standard in regards to the marking scheme.

1 July- 8 June (6th stage): Testing, Mock Competition Runs| Packing, Documentation, Datasheets

Description
F sets up a course; A runs it ONCE. While F swaps the course, A works on fixes in an isolated environment. We will be tracking the score for each run. F will be working on gathering all relevant documents and datasheets. Result
A full scoring sheet with increasing scores as the day progresses. All practice runs from 2024 should have been complete.

## C | Integration Plan

The overarching subproblems can be further broken down into each individual component. We first develop a component, then test its validity within the wider system, creating an iterative design loop and eliminate problems.

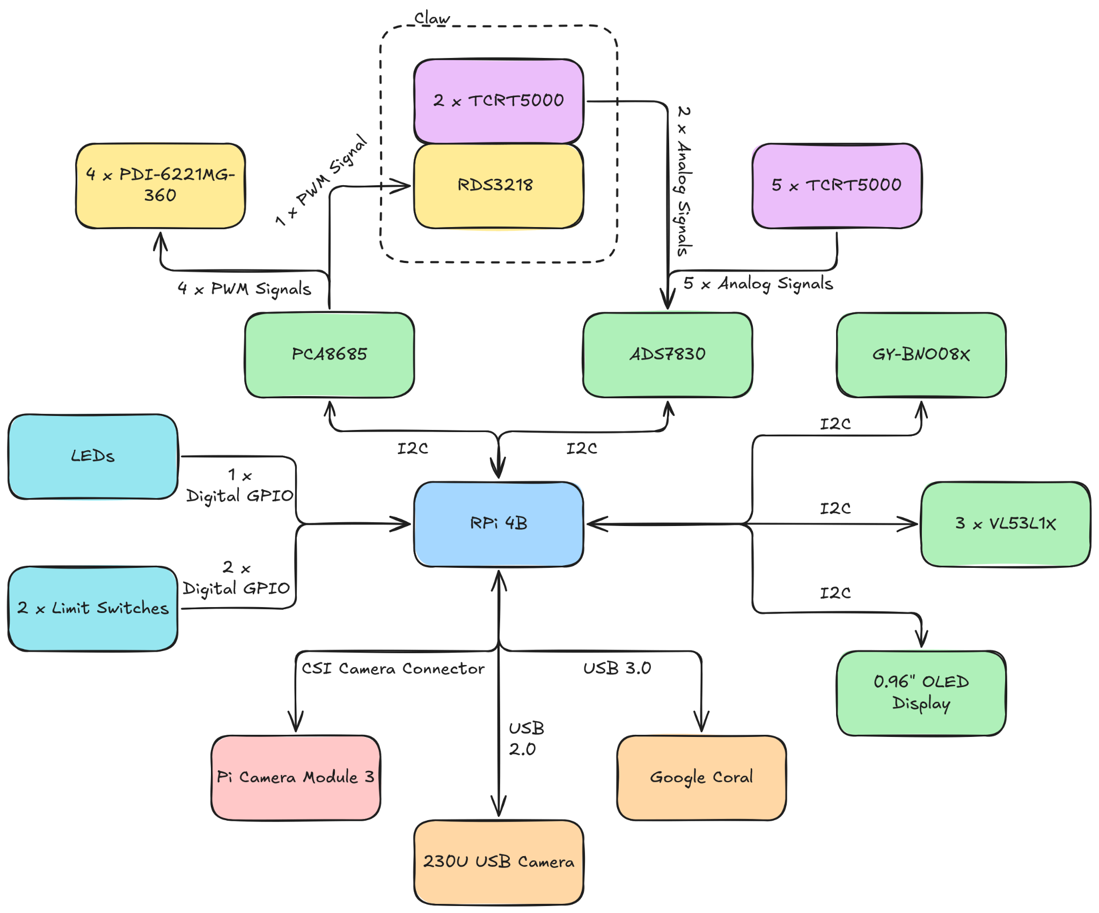
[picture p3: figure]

Microcontroller / Controller

We have decided to use a Raspberry Pi 4B as our main controller for this event. It provides digital I/O, exposes the kernel I2C, with its 40-pin GPIO, CSI camera header, and USB ports, 4GB of RAM, and 1.5GHz clock speed, a clear upgrade from the Raspberry Pi Zero 2W.

Drive chain, Claw (Movement)

We will be using 4 x PDI-6221MG-360, as opposed to the standard DC servos with magnetic encoders, due to the time constraint mentioned earlier; we are familiar with these 360 degree continuous servos as they only require a PWM signal to control. They offer high power (20kg @ 10cm) at 6v, which fits within our power budget. Regarding the claw, we will be using a high-performance 270 degree servo - RDS3218 - that can lift the entire claw mechanism.
Communication: I2C between RPi and PCA8685; generating up to 12 PWM signals

Line follow

A downward pointing Pi Camera Module 3 Wide Angle will be used to filter for the black line, given an image with consistent image. Thus, we have used White COB LED, 5V, 3mm to normalise any shadows. To understand the current terrain the robot is facing, we have included the GY-BNO08X IMU, which accurately relays the current pitch, roll, yaw of the robot. We have kept the colour sensor board, consisting of 5 x TCRT 5000s.

The rules state that speed bumps can have a height of “1 cm or less”. When placed on an incline or tilted tile, proving to be a challenge. To combat the slipping and vibrations, we have decided to create alternative wheels, known as “whegs” out of silicone, which has a high coefficient of friction of ~15.

Communication: CSI camera connector between RPi and Pi Camera; Digital Output between RPi and MOSFET; connecting to the LEDs; I2C between RPi and IMU; I2C between RPi and ADS7830; connected to each TCRT5000 analog output

Evacuation Zone

A forward pointing 2303U USB2.0 camera to view the entire field, at 120 degrees horizontal FOV. We use an SG90 as part of our claw to control picking up and releasing victims, combined with 2 x TCRT 5000s to verify victim colour and presence.

As a backup, we have installed a Google Coral TPU that allows us to use AI inferencing if our current search methods fail during the competition.

Communication: USB2.0 between camera and RPi; I2C between RPi and ADS7830; connected to each TCRT5000 analog output; USB3.0 between RPi and Google Coral TPU

Navigation (Evacuation Zone, Obstacle)

To understand our environment, we have included 3 time of flight sensors, specifically the VL53L1X’s, facing left, right, and forwards. However, they can be inaccurate at times, which is why we have also included limit sensors at the front, for absolute data.
Communication: I2C between VL52L1X and RPi; Digital Input between limit sensors and RPi

Interfacing (Handle, switches, OLED Display)

As a quality of life improvement, to allow for easier debugging, and in accordance with the rules, we have used binary switches and an OLED display to show information without needing a laptop everywhere we went.

Communication: I2C between the OLED display and RPi; Digital Input between binary switches and RPi

# 3 | Hardware

Our goal was a small, low centre of gravity, light chassis robot. To accomplish this, we combine CAD modelling with 3D printing with PLA, giving a free-form structure, optimizing the required space for basic structures, as well as allowing for rapid development and iteration, and giving space to grow.

The basis of our design rests on the chassis: separated into layers, we are able to utilize the z-axis much more efficiently, stacking components directly on top of each other. At the very bottom of the stack, we have the colour sensor board and LEDs, then the drive train and line-follow camera, followed by the various small components and sensors, then finally the controller and battery pack. However, the power train and associated voltage regulators are laid at the back for easy access and visibility. Finally, at the front of the robot, the claw reserves space at the top for its movement capabilities, while we place the evacuation-zone camera below it, as well as the various ToF sensors.

This layout is efficient as there are plenty of options for wires to be routed while keeping the design compact. A key element of this is being able to have two robots available for debugging, due our low cost of production.

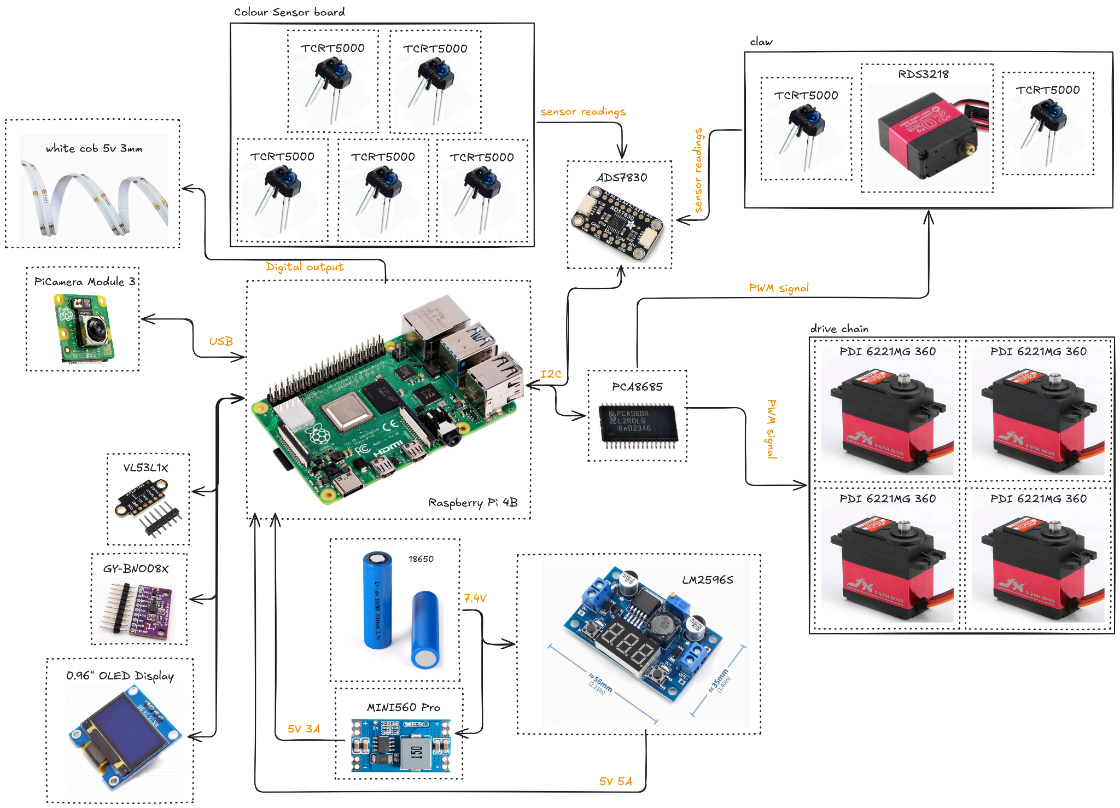
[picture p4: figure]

## A | Mechanical Design and Manufacturing

Chassis

Printed with PLA at 3mm thickness, our chassis provides the rigidity necessary for the small robot and maintaining a small footprint. We have split the robot into separate bases (servo, bottom, back, front, back, battery, and controller) and frames (lower parts, IR sensor, LEDs) that connect and hold all the components together, utilising the z-axis to its fullest. We connect each layer with standoffs of consistent heights, allowing wires to run between each layer. We tested and validated these placements and sizes firstly through visualisation within the CAD, then 3d printing and testing with the real components. This ensured that everything fit together and the entire assembly was viable.

Wheels

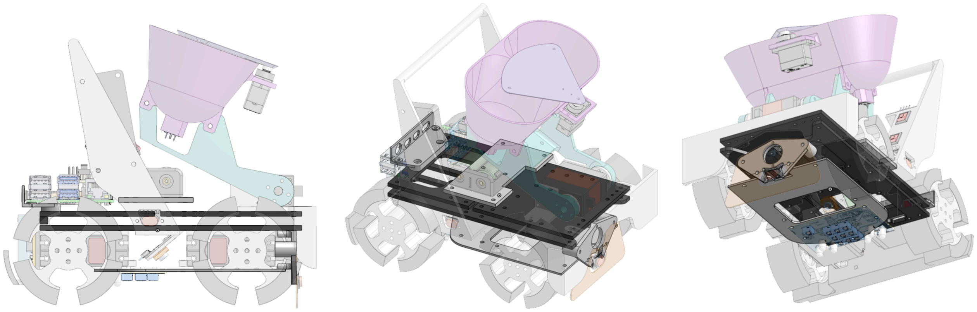
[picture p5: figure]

This year, we have replaced our standard rubber wheels with custom silicone “whegs” (wheel legs). The choice of silicone as our base material is due to its high CoF of 15, providing the much needed grip whilst going on various inclined or tilted tiles. The term “wheg” is coined from the combination of wheel legs: by removing parts of the circumference, we create a broken circular shape, leaving notches, and allowing the wheels to use leverage in lifting itself past speedbumps.

Thus, this hardware solution enables us to navigate even the most difficult terrain, and fulfills our goal of maintaining control in every terrain situation.

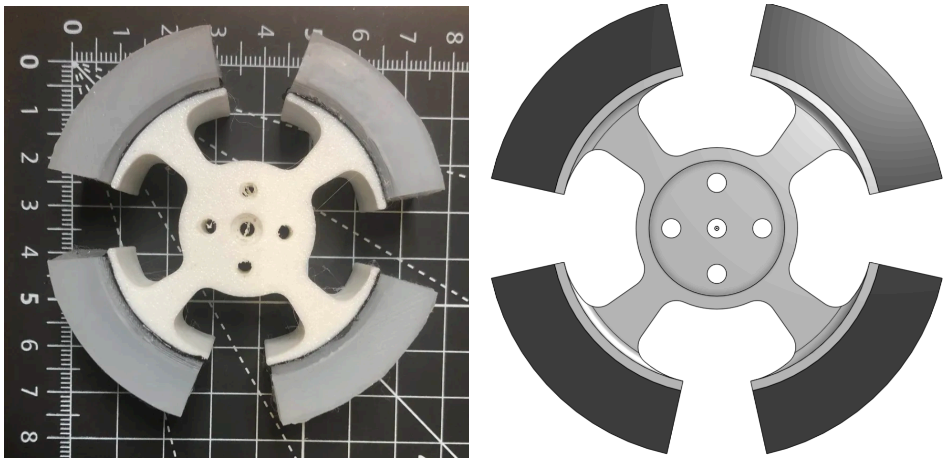
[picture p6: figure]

There were many designs leading up to this, and we validated each through testing each with the same robot setup, only swapping wheels. Our test configuration was uphill, uphill with speed bumps, downhill, and spinning on an incline, and we visually confirmed each challenge passed and the robot was in control.

Rescue mechanism

Our goal regarding the rescue mechanism is to switch from the present 3-bar-linkage, single actuator claw to a two stage claw as further testing of the old system revealed that “Speed bumps may also be placed anywhere in the evacuation zone” would fail any attempt at grabbing the victim, as it relied on the claw being flat on the ground. Thus we have pivoted and changed to a cupping system, where victims are encapsulated and held, which is a more flexible system as it works regardless of what is on the floor. This fulfills our goal of creating a claw that is effective in every situation.

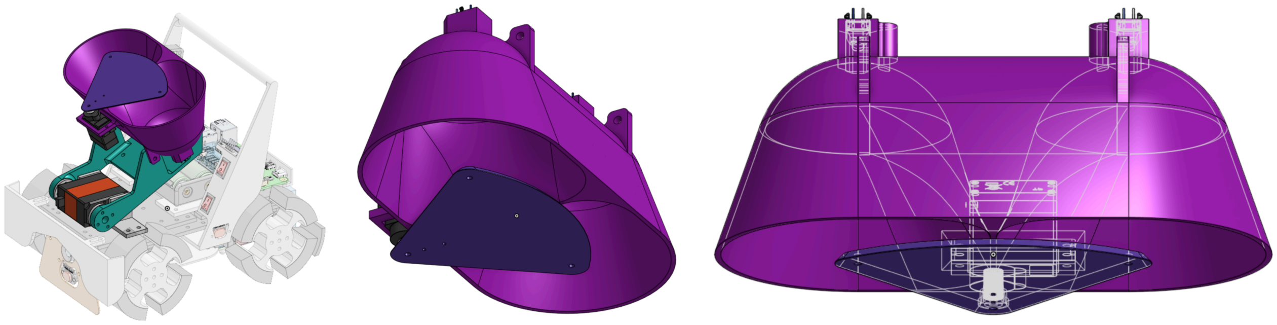
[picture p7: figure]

By holding the ball in a set position, and then closing the bottom, we do not let the victim escape - enclosing it and allowing us to place TCRT5000’s to allow us to read what is currently inside the claw (nothing, dead victim, live victim).

This claw is a straight improvement from our last one, having a capacity of up to two victims. This includes the ability to selectively dump, which could be interpreted as real-time sorting. Compared to other teams, our claw has an advantage of having less mechanical parts. We do not have a separate holding container, fulfilling our size constraint.

To verify that this hardware works, we tested each version of the claw against different sized victims (40mm and 50mm diameters), different weights and different materials. Furthermore, we created a moments calculation which verifies that the servo does have enough strength:

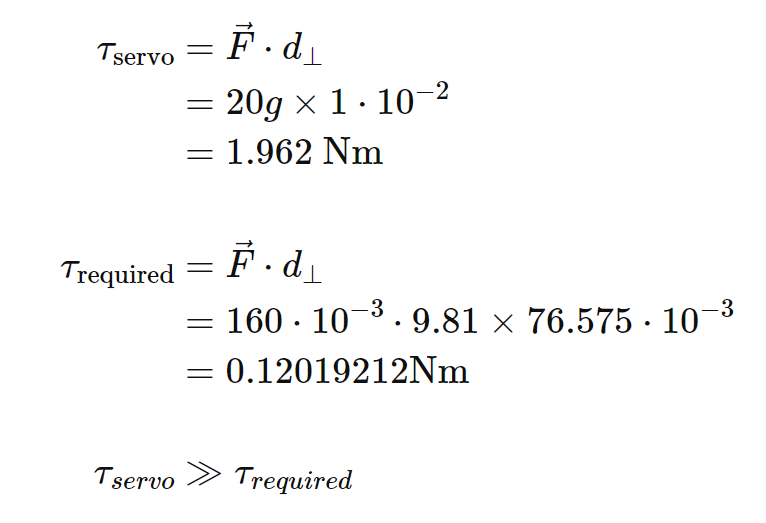
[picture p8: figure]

Physical sweeper

We have encountered debris that ruined multiple of our runs as it blocks the line from being seen, regardless of camera or colour sensor, making following the line extremely difficult as critical information was lost. To solve this, we create a physical sweeper that drags along the floor and pushes all debris in front of the camera along as the robot moves forwards, ensuring none of the debris moves into the camera image and blocks vision. We accomplish our goal of maintaining consistent information with this sweeper.

We will test the shape and the height of the sweeper by dragging it along the floor with a straight tile, and placing various pieces of debris. We ensure all debris is swept away.

Innovative designs

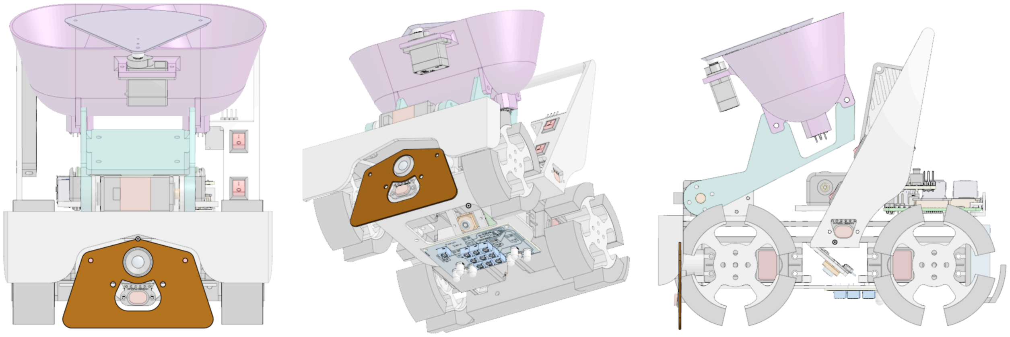
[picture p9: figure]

We consider our rescue mechanism, wheel, and sweeper to be innovative designs, as we haven’t seen any other teams employ such tactics, giving us a substantial competitive advantage. Our rescue mechanism that combines both storage and sorting allows our robot to be extremely small, making maneuvering much easier around the course. Furthermore, our wheel’s design is suitable across a wide variety of terrains, and thus both line follow and design complexity is reduced with its reliability. Finally, the TPU sweeper is printed in blue, and drags along the floor, removing all debris. It also allows the downwards facing camera to see it when it has been reflected off the silver entrance tape to the evacuation zone, allowing us to detect the entrance.

## B | Electronic Design and Manufacturing

For all PCB designing, EasyEDA was the software of choice for its ease of use and cloud service. For ordering PCBs and assembling physical boards, JLCPCB was the service of choice, and we manually bought all components.

Power delivery system

To keep in compliance with our small footprint, we had to use 2 x 18650 batteries which could supply, at a nominal voltage, of 7.4V (8.2V peak). There are 3 major systems upon our robot: controller, sensor stack, and actuators. We use a large DC-DC Buck converter (LM2596S) capable of outputting 6V 5A, and a MINI560 Pro 5V regulator, capable of 5V 3A. With this setup, we are able to drive actuators at 6V’s, and only reach a max current draw of 4A. The MINI560 Pro powers the Raspberry Pi 4, as it only draws 1A under load, leaving 2A of headroom for the rest of the sensors, operating at either 5V or 3.3V.

We measured the success of this method by firstly measuring the current draw of each component or finding it within the datasheet, allowing us to find the input power necessary for all the large components.

Sensors

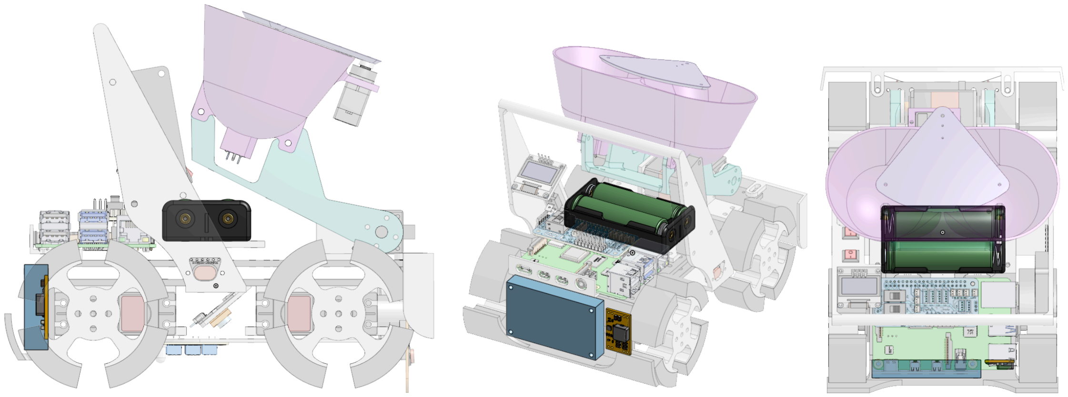
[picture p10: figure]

To gather data about the environment for the robot to make confident decisions, we have many on-board sensors. Firstly, ToF VL53L1X sensors handle measuring the distances in the 3 cardinal directions. Second, limit sensors placed at the front provide absolute data regarding collisions at the front of the robot. An IMU allows the robot to track its pitch, roll, and yaw, indicative of inclines, tilts, and vibrations. A colour sensor board containing 5 TCRT5000s aids the downwards facing Pi Camera Module 3 Wide Angle where the lighting or angle is inconsistent. To validate victims grabbed, we use another 2 TCRT 5000s to detect presence, or colour (reflective, black).

To validate that all these components work, we developed each sensor by itself with isolated hardware and then coding each module with its appropriate library during the 2nd stage of development.

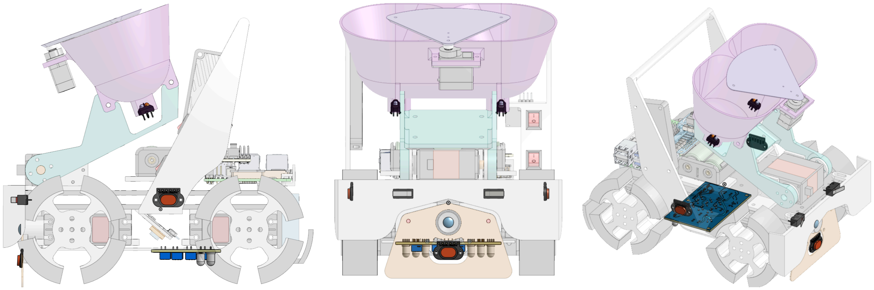
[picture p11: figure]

Controller/Microcontroller

For the international build, we eliminated our old microcontroller entirely by upgrading to a Raspberry Pi 4. With significantly higher processing power, the Pi 4 now handles everything - from PWM control (via PCA9685) to analog sensor parsing (via ADS7830) and real-time vision tasks for two cameras. This shift reduced hardware complexity, improved multitasking, and made the entire system easier to debug and maintain, shown through timing each function call in our program and seeing a dramatic reduction in time taken to execute, thus proving that this upgrade was worth it. This fulfills our goal of supporting two cameras while retaining all other functionality. We do not require a secondary controller due to our shield.

To integrate this new controller, we had to increase the size of the robot and test that all our external sensors were compatible first. Because this is a direct upgrade, there were no issues.

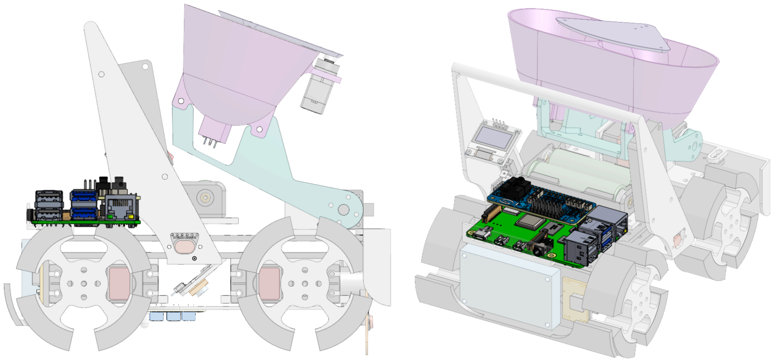
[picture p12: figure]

Custom Raspberry Pi Header Shield

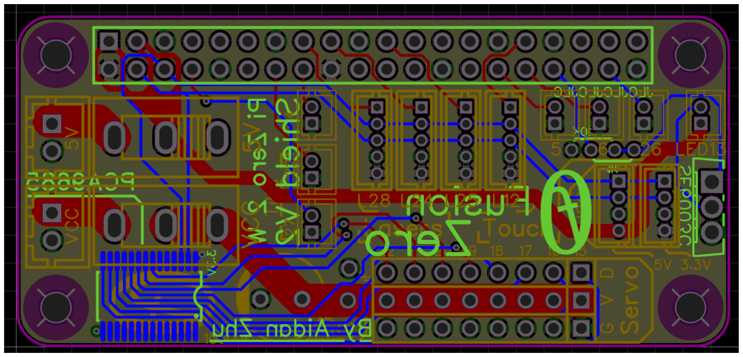
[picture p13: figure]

We designed a 4-layer custom shield to support both the Pi Zero 2W and Pi 4, avoiding the need to redesign the board when upgrading. This shield integrates servo control (PCA9685), MOSFET switching for COB LEDs (a voltage divider to handle 3.3V logic), and decoupling capacitors (1000µF and 0.1µF) for servo stability. All peripheral connectors were upgraded to JST headers for secure, vibration-resistant connections. Breakouts for I2C and GPIO are included for clean sensor integration. The result is a compact, modular hub that reduces wire clutter, improves reliability, and simplifies maintenance during development and competition.

This design has been verified in previous competitions (Japan, Singapore) and works as expected. Additionally, as the new controller has the same 40-pin GPIO headers, the integration with the Pi 4 is seamless.

Colour Sensors

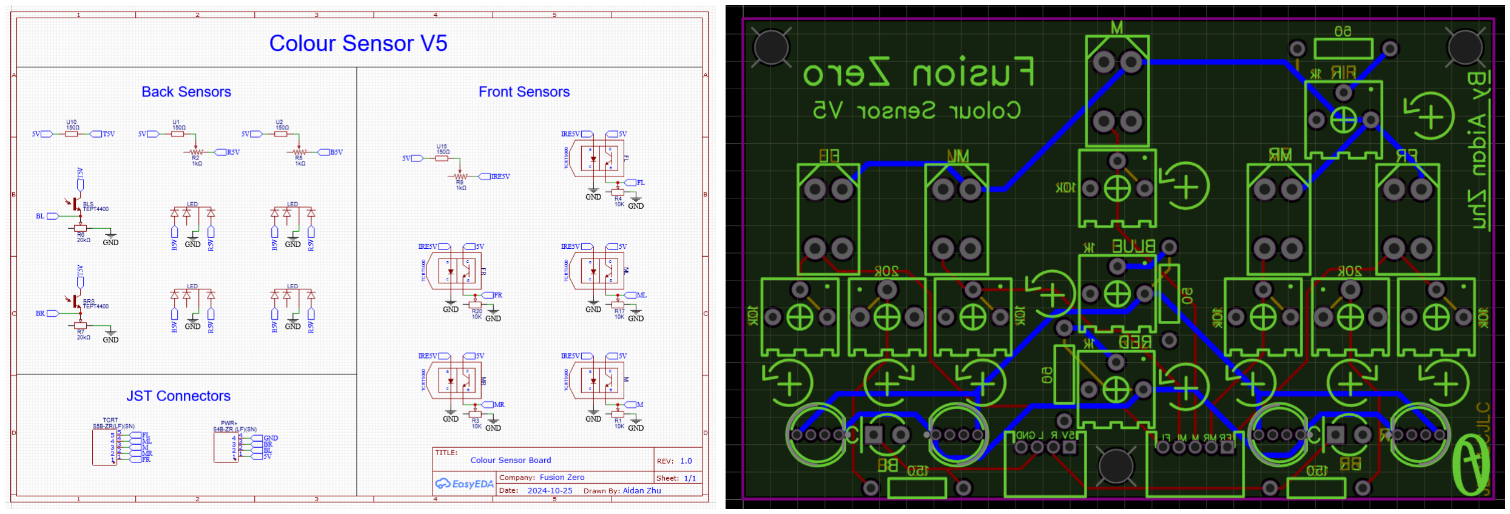
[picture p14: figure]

The TCRT5000s reliably detect black/white transitions during ramp exits, obstacle avoidance, and stuck recovery. Despite our switch to camera line following, this board remains a valuable fallback system.

To integrate, we simply had to create the appropriate frame at the bottom of the robot, but slightly shifted back so the camera could have an unblocked view of the line as well.

Innovative designs

We consider our colour sensor board to be an innovative design as its simplicity is what allows it to be reliable. The high reading frequency combined with their purposeful placement allows it to capture the correct information. Using IR wavelengths makes it immune to changes in the natural light. We also consider our custom Raspberry Pi 40 pin GPIO header to be innovative, as it enables many features that we would otherwise lack without a secondary microcontroller. Finally, our smart choice of the Raspberry Pi 4 enables us to only use 2 x 18650s, allowing us to constrain our footprint as much as possible.

# 4 | Software

Our Raspberry Pi runs Python 3.9 with numpy, opencv, and multiprocessing as our main constructors of the program. The entire system runs through a single process, except for the mode switching, which is processed in another thread such that state interrupts such as switch toggles are detected. We use the specified library developed by adafruit for every sensor we have, which abstracts the data handling from the hardware level. We use an object oriented programming paradigm as a scaffold, and combine it with an imperative style to yield the expected behaviours. To ensure the robot is predictable, many loops are governed by a closed-loop feedback system. We utilize our OLED screen and the console for debugging.

We use VSCode with the Remote-SSH extension to connect and run code within the robot over a wireless network. As backup, we have also set up the RPi to be an ethernet device that can be connected to over physical USB-C. Tools like ChatGPT, Claude 4.0, and Perplexity allowed us to research and develop our code at a much faster pace. Github acts as our versioning software, allowing each team member to work in parallel. Integration of code is seamless through this versioning, as well as our mode-selector which allows us to test various components before appending to the main program loop.

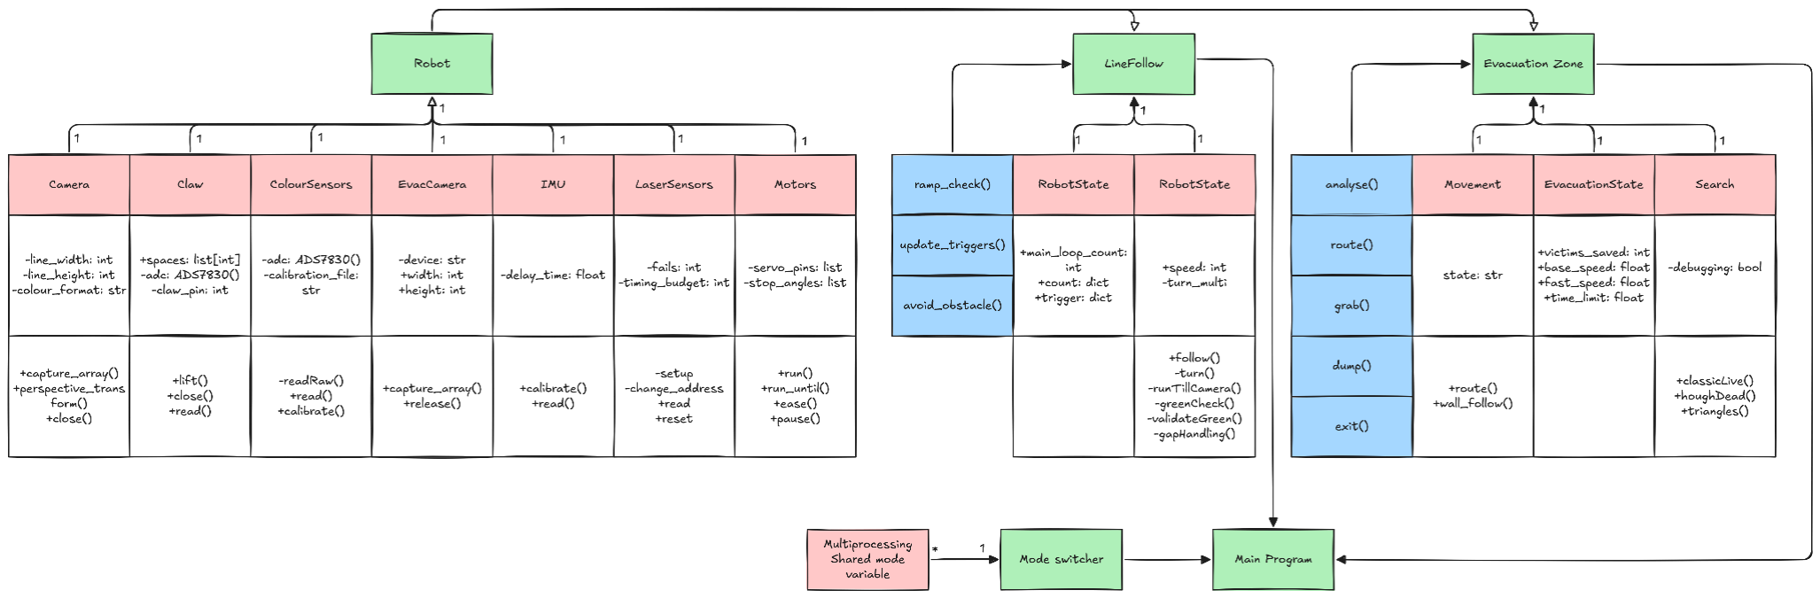
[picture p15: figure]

## A | Line Follow

During the line-follow portion, our robot uses cv2 alongside all the sensor libraries. We perform computer visioning, finding black and green contours, and using our custom algorithm to determine the correct direction our robot needs to go. This process is controlled by a closed-loop feedback system with P (proportional gain) only.

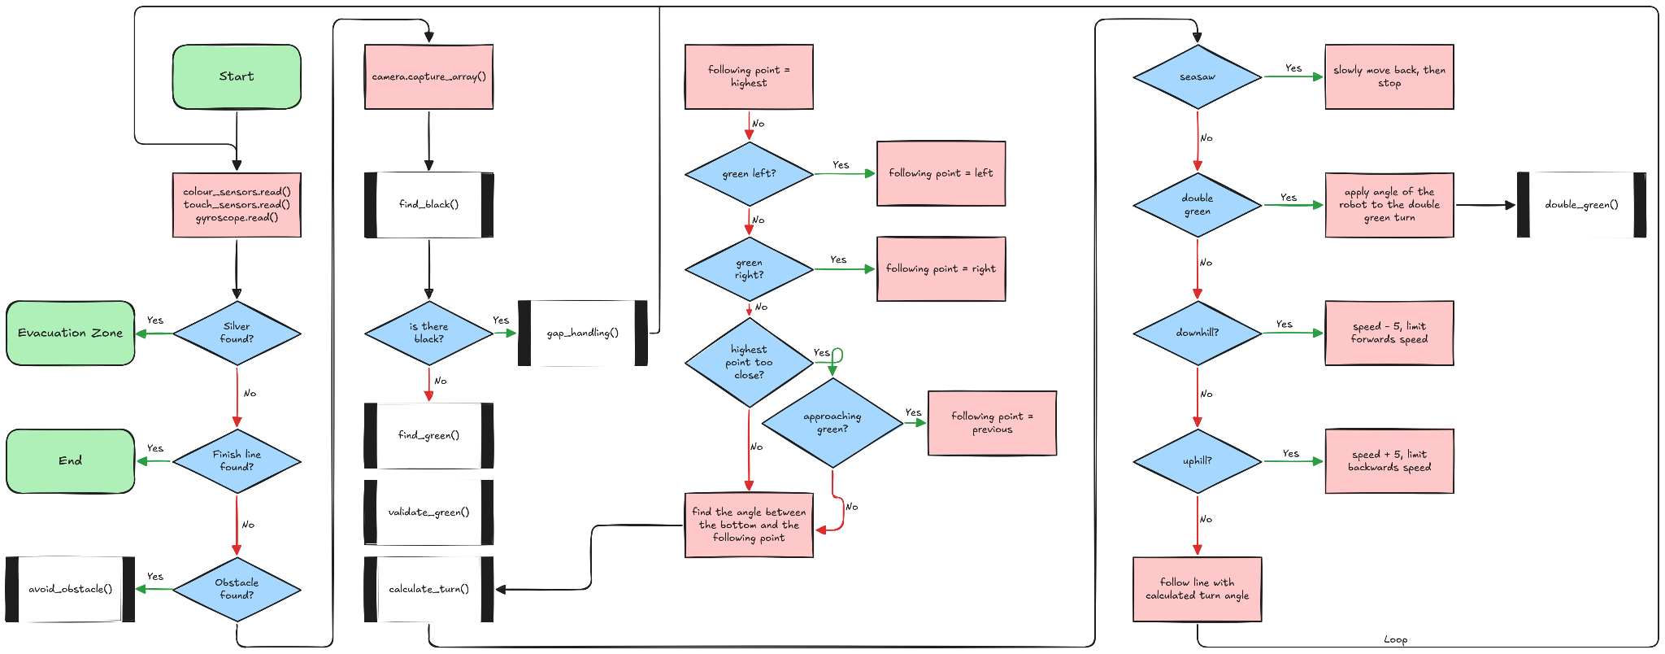
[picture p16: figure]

We first take in all the sensor information (colour sensor, touch, gyroscope) to determine the best course of action, such as switching to evacuation_zone or avoiding an obstacle. If no external conditions are applied, then we have to be line following. By taking contours of black and green, we are able to calculate the angle between a virtual following point and the bottom of the camera image accounting for intersections. This virtual following point is set in different positions depending on the line and intersection. For testing and quality control, see testing. To integrate, we simply commit into the line_following branch in Github, occasionally creating PRs to get the new hardware updates.

## B | Evacuation Zone

During the evacuation zone portion, our robot uses cv2 alongside all the sensor libraries. We perform computer visioning, finding all objects of interest, and routing to and performing the appropriate action with a closed-loop feedback system.

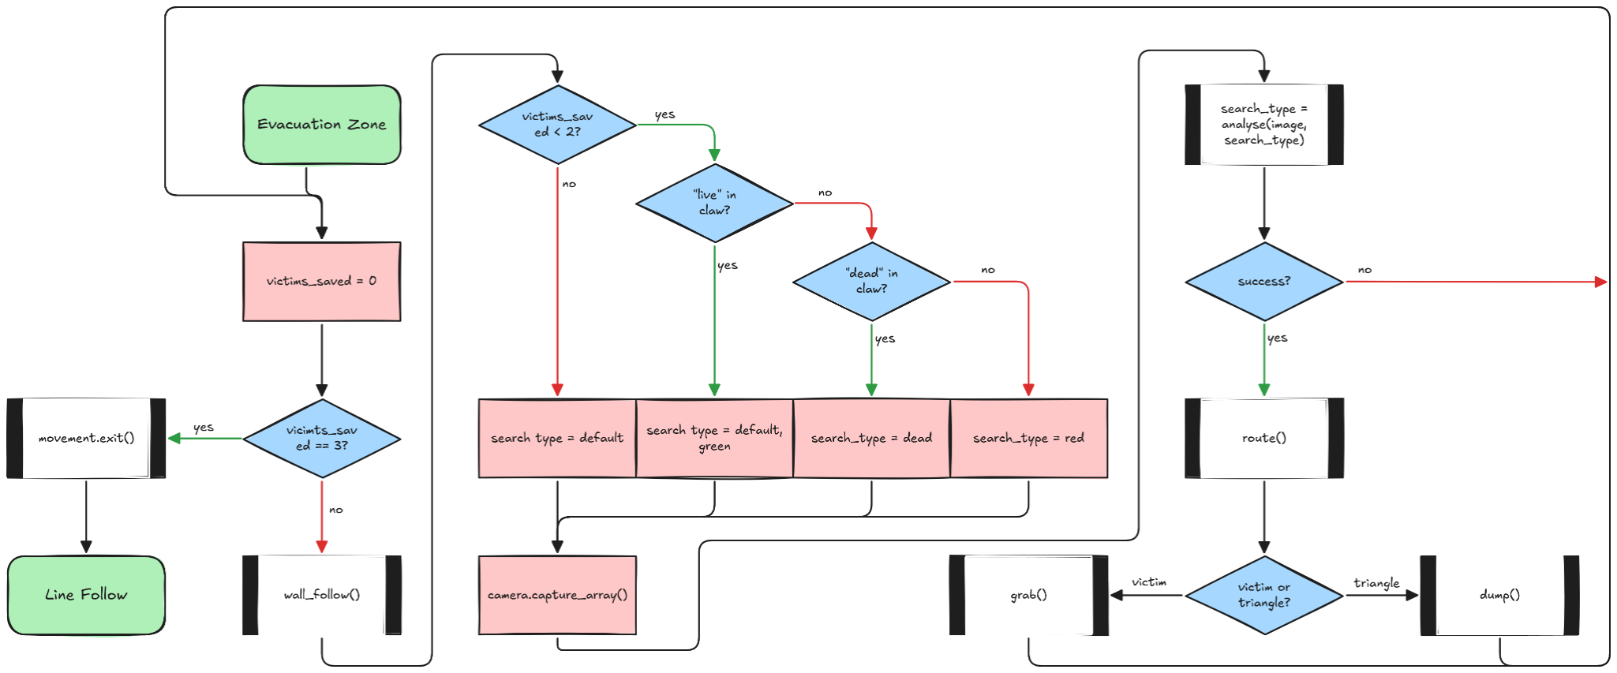
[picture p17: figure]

Our main evacuation loop simply follows the boundary of the evacuation zone. This strategy allows us to cover the entire playing field, as well as find different, more suitable angles for grabbing. Following, we select which objects are of interest based on the current number of victims saved and what the claw has. If an object is found, we attempt to route to it using a closed loop feedback system using the object’s x position within the camera frame. Finally, when all victims have been found, we follow the wall and find the exit again.

To find these objects of interest, there are several key components necessary. For live victims, our entire algorithm exposes the repetitive setup and environment in any competition and at practice - silver coloured victims are often made from metal, and thus contains a reflective property, truly reflecting light. These create “spectral highlights” which are always apparent and visible to our camera. Instead of searching for victims, we can simply search for these reflections that only exist on live victims. For dead victims, there is great contrast between the black sphere and white background, and thus we can mask the original image for the dark pixels and the area surrounding it. Next, we are able to run a HoughCircle algorithm which allows us to locate the victim while checking for the circularity of any object. Finally, for the triangles, we can simply mask for vivid green and red colours with an HSV colour space, and then find the relevant contours and centre of mass. For testing and quality control, see Evacuation Zone. To integrate, we simply commit into the evacuation_zone branch in Github.

## C | Innovative Solutions

Our line following algorithm also allows us to account for tilted or inclined boards with full line following capabilities. This is done through limiting the range our motors can run at, allowing us to maintain control at various rolls and pitches, while understanding how to turn without losing the line. Furthermore, the adaptive following point allows us to anticipate intersections and handle a greater variety of cases, which fulfills our overall goal of becoming more robust.

Due to previous hardware issues, we were forced to develop alternative ways to identify victims. We think our approach is much more efficient as we do not require active cooling and the Google TPU that would increase the robot’s footprint and power draw. We exploit the predictable nature of the competition venue to our advantage, and thus we constrain to our small footprint goal. However we still acknowledge the reliability of the AI technique and endeavored to create a suitable model in case our approach does not work.

Finally, to identify the silver tape that marks the entrance to the evacuation zone, our clever sweeper design printed in blue TPU is reflected off the tape. What usually would not be in the camera frame is now visible, and thus we can perform a simple blue mask and contour check to identify if there is an entrance. Furthermore, as we still have retained our colour sensor board, we have extra verification. We reduce the complexity of this problem that previous teams required AI by relying on colours that are not present anywhere else within the competition.

# 5 | Performance Evaluation

## A | Testing procedure

Remember that all development and evaluation is part of the iterative cycle: each problem identified always leads to a hardware or software solution. Our team has been able to develop two robots such that these two parts of the competition can be developed simultaneously, alongside hardware improvements.

Line Following

When testing line following, and other assorted components, it is clear that we needed variation in our board. Thus, using PVC foam boards, we created all our boards by hand. Using electrical tape and a craft knife allowed us to create black lines of varying widths. Using green electrical tape from different brands got different shades of green, cut using the craft knife. This meant that our tiles replicated the conditions found in competition. We modelled our own ramps, seesaw, obstacles in Onshape, and 3d printed them. Using some wood standoffs and white tape, we were able to create boards at higher elevations. We will evaluate performance based on a percentage success for each tile in various configurations, such that we could slowly categorise it into “easy” and “hard” tiles.

Stage 2 would focus on the basic line follow algorithm. This entails a simple, flat line following with what we classify as common tiles: easy tiles with little turns, but no intersections, resulting in a consistent line follower, verifying our ideas regarding camera line following. We used this stage to iterate on the appropriate camera angle, as well as the LED placement, quantity, and diffusion level. Stage 3 introduced all variations (gaps, speed bumps, intersections, obstacles, tilts, inclines), replicating the expected level of difficulty. Stage 4 introduced the international difficulty, as many rounds are full of debris and speed bumps placed at awkward angles, as well as freeform boards that we had not seen before in competition. This added difficulty allowed us to test various, new conditions, simulating a competition.

A problem that has plagued our team is our inability to overcome inclines and tilts due to poor configuration. Leading to the competition, we have tested 3 materials and 4 different wheel designs. This led to the best hardware change which reduced the complexity of line follow tenfold. As previously explained, we finally settled for silicone with the “wheg” wheel design with silicone. Another problem could be the transition between uphill - flat ground. The LEDs cannot counteract and light up an empty void, thus many pixels are considered “black”. Our solution to this was simply limiting the vision of our robot to not include this by manually cropping the image.

Evacuation Zone

By developing a jigsaw pattern, we were able to laser cut pieces that fit together and provided a transportable evacuation zone. The walls of the evacuation zone are fully 3d printed, and can be slid out, allowing for customizable entrance/exit combinations. The evacuation points are created with the PVC foam boards glued together. We have bought silver, reflective spheres off Aliexpress at diameters 50mm and 40mm. Furthermore, using Onshape and rice, we have created 45mm weighted spheres wrapped in tinfoil or electrical tape.

Stage 3 includes simply being able to identify, route, and grab or dump the object of interest. This forms the core evacuation loop, so it is important that this is done properly. By testing at different times of day, and with various ball weights, sizes, and triangle locations, we had simulated many common positions that could occur during competition. Stage 4 introduces the complete routine, including entry and exiting into and out of the evacuation zone, as well as handling obscure cases such as obstacles being placed. Furthermore, the wall-follow algorithm is refined with sensor fusion with the IMU.

A problem we faced was verifying that we picked up a victim. Our claw would temporarily block the front camera’s vision, and when it was lifted again, there would be no guarantee that the victim had not moved. Thus, we integrated TCRT5000s into the claw, reading into the remaining analog inputs on the ADS7830. This simple solution provided great value, as it also saved computational power as now we had confirmation on what tasks were remaining within the evacuation zone. Another problem we’ve consistently faced is the issue of wall-following. Due to our limited laser sensors on the side, trying to run a feedback loop with no true information, only a set value, leads to difficult navigation. This competition, we refined the algorithm by introducing a virtual pivot point which delayed the turning effect.

## B | Full mock runs

Stage 5 tests the transitions between line following and evacuation zone. Stage 6 will run full mock competitions, where we would build the previous years courses, run them a single time, and score them. As one team member works on assembling the next course, the other will practice our competition routine of creating a new branch and modifying the relevant code that the robot failed on. This trains our ability to work under pressure, generate new ideas with little to no testing environment. Furthermore, this allows us to accurately track how scoring and points work, and when we need to skip checkpoints depending on the time left.

# 6 | Conclusion

Fusion Zero is a team that prides itself in its extensive testing, small robot, and innovative hardware and software decisions. From custom wheels to exploiting predictable environments, our robot performs consistently and reliably, avoiding touches and deduction of points by playing slow and maximising our time to the 8 time limit.

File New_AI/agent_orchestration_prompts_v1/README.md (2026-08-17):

# Orquestracao de Agentes - FusionZero OBR (Pi4)

Esta pasta contem prompts prontos para executar a refatoracao em **New_AI** sem mexer no resto do repositorio.

## Regra critica (todos os agentes)
- Trabalhar **somente** em: `New_AI/obr_overengineering_v1`
- **Proibido** editar: `pc_vision_ui.py`, `pc_vision_runner.py` e qualquer arquivo fora de `New_AI`.
- Reutilizar o que ja existe no FusionZero antes de criar implementacoes do zero.

## Referencias visuais
- `New_AI/Pasta de fotos para inspiração e uso , quero deixar igual/`

## Referencias tecnicas legadas para reuso
- `pc_vision_ui.py`
- `pc_vision_runner.py`
- `1_international/behaviours/silver_detection.py`
- `5_ai_training_data/0_models/silver_line/silver_detector_pi4_quantized.pt`
- `5_ai_training_data/0_models/dead_vicitims/dead.tflite`

## Ordem de execucao
Veja `07_WAVES_E_CONCORRENCIA.md`.

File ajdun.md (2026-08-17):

entendi , uma dúvida , percebi que ele parece ter dois modos

1. Modo de seguir linha
2. Modo de Resgate

Gostei muito disso, porém hoje ele se autolocaliza e percebe onde está para trocar de modo
Ainda não temos a silver line para fazer teste ( lembrando que a Silver Line vai marcar quando trocar de modo ) e depois que ele colocar todas as bolas no pote ele volta a procurar linha e onde está a saída.

Me confirma se tem isso mesmo , pois só por enquanto estava querendo colocar um botão para trocar de modo assim fica mais faz de vermos o que está funcionando e não em cada lugar

Em geral após essas mudanças está excelente, mas percebi 3 problemas
1.quando tem red corner e bolas na frente ele detecta normal, mas quando o green corner ele não detecta as bolas , preciso que arrume isso 2. Ele não desenha o quadrado quando tem mais de 1 bola para silver ball , ele buga e fica trocando entre as duas para reconhecer , gostaria que reconhecesse e desenhasse nas duas , se quiser podemos treinar um modelo ( mas não sei se é necessário ) para indicar quando tem 1 e quando 2 , só quero fazer isso se realmente for ficar muito melhor e não tiver como deixar absurdamente bom do jeito que está arrumando só para ele reconhecer duas ao mesmo tempo 3. ele detecta green corner e green ao mesmo tempo , ele ainda não sabe diferenciar os dois , ATENÇÃO --> NÃO MEXA NO GREEN NORMAL DOS QUAFDRADOS QUE FICAM NO SEGUE LINHA ELES ESTÃO PERFEITOS , mexa no Green Corner , ele está muito ruim está ao mesmo tempo verde e green corner
quero tenha mensagem igual red corner e quero nível de confiança também , nos quadrados da linha quero o quadrado desenhado também e o núvel de confiança também e as setas mudando ( já estão ) só estou falando de novo

Veja que na foto onde tem um quadrado e linha ele coloca como 100% Green Corner sendo que é um quadrado verde , as setas estão perfeitas só quero a mensagem mude e que seja separado Green Corner e o quadrado verde da pista

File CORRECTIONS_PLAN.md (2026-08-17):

# Plano de Correções e Ajustes Pós-Implementação (Fase de Lapidação)

Este plano deve ser executado no repositório `FusionZero-Robocup-International` **assumindo que as implementações base da Fase 1 a 4 já foram realizadas pelo Codex**.

O foco agora é corrigir assincronias, melhorar os gargalos de visão, calibrar o Red Marker e estabilizar a Interface do Usuário espelhada da _Over Engineering_.

---

## ❓ Esclarecimento sobre o "Clone" (Sobre a Dúvida)

**Os Agentes não deveriam clonar fisicamente o repositório da _Over Engineering_.**
O objetivo orquestrado no plano original (e neste) é **reproduzir a arquitetura visual e intelectual** deles para _dentro_ do nosso código. Clonar e tentar fazer um _merge_ de dois repositórios de robôs diferentes causaria falha catastrófica de dependências de hardware (sensores diferentes, portas seriais diferentes, etc.).

> **Abordagem Correta para os Agentes:** Os Agentes trabalharam exclusivamentne escrevendo código NO NOSSO repositório (`FusionZero-Robocup-International`), criando as classes de Interface, Visão e Event_Bus baseando-se estritamente nas regras ditadas pelos prompts, sem depender de pastas externas.

---

## 🛠️ Diagnóstico Pós-Implementação (Expected Issues)

Assumindo que os agentes já rodaram, os problemas listados abaixo são característicos dessa ponte de integração e devem ser corrigidos pelos respectivos especialistas em uma **Bateria de Correções**:

| Problema Identificado no Integrado | Agente Responsável pela Correção |
| :--- | :--- |
| UI travando por alguns milissegundos enquanto a Visão formata os `cv2.findContours`. | **Agent_UI_Refactor** |
| Cores do traçado no Path 2D estão sumindo rápido ou causando lag com histórico enorme. | **Agent_Path_Render** |
| Falsa detecção de bolinhas laranjas como "Zona de Resgate Vermelha" sob luz de teto. | **Agent_RedColorCalibration** |
| Módulo de Visão ativando a detecção de linha dentro da sala de resgate (desperdício processual). | **Agent_Vision_Optimization** & **Agent_StateMachine** |
| Variáveis de Estado da FSM mudando, mas a UI (`QLabels` no painel superior) não atualiza. | **Agent_UI_Refactor** & **Agent_StateMachine** |

---

## 🤖 Plano de Correção Multiagente (Prompts de Ajuste)

Para disparar no **Codex**, foque em passar o contexto do erro específico junto com estes prompts de correção.

### 🔴 Agente: Agent_UI_Refactor -> (Correção: Desengasgo do Qt)

**Bug a corrigir:** A interface congela momentaneamente na exibição de muitos frames (gargalo da Main Thread). O status textual da FSM ("... Following Line ...") não está mudando reativamente.
**Arquivos alvo:** `src/ui_overengineering/dashboard.py` (ou onde o PyQt6 foi montado).
**Prompt de Correção para Codex:**

> ATUAÇÃO: Agent_UI_Refactor. MODO: Debug & Fix.
> TAREFA: O Dashboard recém implementado em PyQt6 está sofrendo de frame-drops e congelando a Main Thread. Você deve refatorar o loop de atualização de imagens (`update_frame`).
>
> 1. Converta a emissão do Frame pelo módulo de Visão em um `pyqtSignal(np.ndarray)` assíncrono.
> 2. As imagens recebidas devem ser redimensionadas (`cv2.resize`) em uma QThread separada ANTES de serem enviadas ao `QLabel` principal via `QPixmap`.
> 3. Na barra central-superior de eventos FSM, garanta que ela possui um Observer local conectado ao `Event_Bus` via um `pyqtSlot` (Slot-Signal Qt puro), para alterar o texto instantaneamente de "... Following Line ..." para "... Picking up alive victim ...".

### 🔴 Agente: Agent_RedColorCalibration -> (Correção: Falso Positivo Luminoso)

**Bug a corrigir:** O filtro vermelho está abrangendo laranja escuro ou tons de madeira. Formas não retangulares estão sendo aceitas como borda final de resgate.
**Arquivos alvo:** Módulo responsável pelo processamento de contornos vermelhos.
**Prompt de Correção para Codex:**

> ATUAÇÃO: Agent_RedColorCalibration. MODO: Debug & Fix.
> TAREFA: A detecção dupla de HSV implementada está com range muito flexível. Aplique uma restrição aguda: O range inferior deve ir de [0, 150, 100] a [8, 255, 255] e o range superior de [170, 150, 100] a [180, 255, 255]. Aumente drasticamente a exigência mínima de Saturação (S) para matar laranjas e marrons. Além disso, reforce a função de `identify_red_context`: Injete validação de polinômio `cv2.approxPolyDP`. Se for a linha vermelha da pista, o bounding box DEVE ser estreito e longo. Se for sala de resgate, DEVE ser um mancha disforme vasta ou contorno côncavo. Expurga contornos abaixo de 500 pixels de Área (`cv2.contourArea`).

### 🔴 Agente: Agent_StateMachine + Agent_Vision_Optimization -> (Correção: Otimização Condicional)

**Bug a corrigir:** A YOLO ou o detector de círculos continua rodando na rampa, fazendo a temperatura da CPU bater 80%+.
**Arquivos alvo:** `state_machine.py`, `vision/pipelines.py`
**Prompt de Correção para Codex:**

> ATUAÇÃO: Agent_Vision_Optimization e Agent_StateMachine. MODO: Debug & Integratrion Fix.
> TAREFA: A arquitetura atual de FSM não está cortando funções pesadas. Refatore `vision/pipelines.py` injetando uma leitura rigorosa do `current_state` da Máquina de Estados.
> Regra Absoluta: Se estado == SEARCHING_LINE ou FOLLOWING_LINE ou VALIDATING_GAP -> RETORNE IMEDIATAMENTE antes de carregar modelo neural de resgate (YOLO/HoughCircles). Apenas rode Binarização Preta para linha.
> Se estado == RESCUE_ZONE_DETECTED -> Desative a máscara negra (Binarização), e ligue 100% dos recursos visuais no tracking de Vitimas Vivas (Prata) / Mortas (Preta). Faça com que a mudança de estado propague um Log severo demonstrando a economia de pipeline no buffer.

### 🔴 Agente: Agent_Path_Render -> (Correção: Estouro de Memória)

**Bug a corrigir:** Histórico do Path Canvas infinito derrubando a memória gráfica ao longo de tempos superiores a 3 minutos simulados. O buffer 2D fica lotado de pontos sobrepostos.
**Arquivos alvo:** componente de Path 2D (Renderizador do traçado Azul).
**Prompt de Correção para Codex:**

> ATUAÇÃO: Agent_Path_Render. MODO: Debug & Fix.
> TAREFA: Refatorar o renderizador 2D. Troque o cache acumulativo infinito de arrays por um buffer estático usando `collections.deque(maxlen=1000)`. Se o robô ficar parado enviando coordenadas iguais, não adicione-as na Deque de rastreamento (implemente distância Euclidiana mínima antes de salvar um `(x,y)` novo). Desenhe apenas os segmentos de linha em um Surface pré-compilado ou no canvas, evitando que o PyGame/Qt reconstrua todos os 1000 vetores desde o início a cada Frame de 30FPS.

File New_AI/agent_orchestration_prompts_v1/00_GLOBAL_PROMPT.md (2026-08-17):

# Prompt Global (enviar para todos)

```text
Contexto comum para todos os agentes:
- Objetivo final: criar uma nova arquitetura OBR desacoplada em New_AI, com PyQt6 + Event Bus tipado + Vision orientada por FSM, focada em Raspberry Pi 4 (4GB).
- Entregavel final esperado: sistema em `New_AI/obr_overengineering_v1` sem alterar os arquivos atuais que ja funcionam.

Restricoes obrigatorias:
1) Trabalhar somente em `New_AI/obr_overengineering_v1`.
2) Nao editar nem mover `pc_vision_ui.py` e `pc_vision_runner.py`.
3) Priorizar precisao + desempenho no Pi 4.
4) Evitar bloqueio da thread da UI.
5) Reutilizar ao maximo os detectores/modelos do FusionZero.

Reuso obrigatorio (referencia):
- LineDetector, BallDetector, ColorMarkerDetector de `pc_vision_runner.py`.
- Estrategia de status/FPS/composicao da `pc_vision_ui.py`.
- SilverLineDetector de `1_international/behaviours/silver_detection.py`.
- Modelos: silver_detector_pi4_quantized.pt e dead.tflite.

Direcao visual obrigatoria:
- Dashboard escuro estilo Overengineering.
- Duas views no topo (raw/processado), telemetria, estado textual curto, timer principal grande, bloco central de robo placeholder.

Regra de comunicacao:
- reportar progresso em blocos curtos.
- listar bloqueios explicitamente.

Formato de status obrigatorio:
Agent: <agent_name>
Status: <not_started|in_progress|blocked|done>
Completed:
- <item>
Next:
- <item>
Blockers:
- <item_or_none>
Artifacts:
- <file_or_result>
```

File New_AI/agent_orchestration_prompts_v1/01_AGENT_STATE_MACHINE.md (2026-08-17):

# Agent_StateMachine

```text
Voce e o agente Agent_StateMachine, com papel de Planner Architect + Integrator de contratos.

Missao:
Implementar FSM formal e Event Bus tipado para governar todo o sistema.

Escopo permitido:
- Criar `New_AI/obr_overengineering_v1/src/core/event_bus.py`
- Criar `New_AI/obr_overengineering_v1/src/core/state_machine.py`
- Criar/atualizar `New_AI/obr_overengineering_v1/docs/interfaces.md`

Escopo proibido:
- Alterar qualquer arquivo fora de `New_AI/obr_overengineering_v1`
- Colocar logica de visao pesada dentro da FSM

Entradas obrigatorias:
- IMPLEMENTATION_PLAN.md
- 00_GLOBAL_PROMPT.md

Estados obrigatorios:
- SEARCHING_LINE
- FOLLOWING_LINE
- VALIDATING_GAP
- CROSSING_GAP
- VICTIM_FOUND
- RESCUE_ZONE_DETECTED

Eventos obrigatorios:
- ON_GAP, ON_LINE_FOUND, ON_LINE_LOST, ON_VICTIM_DETECTED, ON_RESCUE_RED_DETECTED, ON_INTERSECTION, ON_TIMEOUT, ON_RESET

Passos:
1) Definir enums de estados/eventos e tabela de transicoes valida.
2) Implementar EventBus pub/sub thread-safe com payload tipado.
3) Publicar logs de transicao: `TIMESTAMP [STATE] msg`.
4) Congelar contrato `interfaces.md` v1 para os outros agentes.

Formato de saida:
- Tabela completa de transicoes
- Topicos oficiais
- Schemas dos payloads
- Riscos restantes

Definicao de pronto:
- FSM deterministica
- Event bus funcional com fila limitada
- `interfaces.md` v1 pronto para integracao

Handoff:
- Entregar para UI, Vision, Path e TestValidation.
```

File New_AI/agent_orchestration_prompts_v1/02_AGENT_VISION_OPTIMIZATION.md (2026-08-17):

# Agent_Vision_Optimization

```text
Voce e o agente Agent_Vision_Optimization, com papel de Builder Vision.

Missao:
Refatorar visao para pipeline modular por estado, com reuso maximo do FusionZero e foco em Pi4.

Escopo permitido:
- Criar `New_AI/obr_overengineering_v1/src/modules/vision/preprocessor.py`
- Criar `New_AI/obr_overengineering_v1/src/modules/vision/pipelines.py`
- Criar `New_AI/obr_overengineering_v1/src/modules/vision/vision_node.py`
- Criar `New_AI/obr_overengineering_v1/configs/vision_config.json`

Escopo proibido:
- Alterar qualquer arquivo fora de `New_AI/obr_overengineering_v1`
- Rodar todos os detectores em todo frame

Entradas obrigatorias:
- `pc_vision_runner.py`
- `1_international/behaviours/silver_detection.py`
- `5_ai_training_data/0_models/...`
- `docs/interfaces.md`

Reuso obrigatorio:
- Portar/adaptar LineDetector, BallDetector e ColorMarkerDetector.
- Integrar SilverLineDetector com `silver_detector_pi4_quantized.pt`.
- Preparar opcional de dead victims com `dead.tflite` (rescue state).

Passos:
1) Implementar preprocessamento (ROI + CLAHE + morfologia + ajuste por luma opcional).
2) Implementar `switch_pipeline(estado)`.
3) FOLLOWING_LINE: linha + verde + vermelho + silver line.
4) RESCUE_ZONE_DETECTED: bolas/vitimas/vermelho de zona; desativar linha.
5) Publicar resultados em `vision.detections` com `latency_ms`.

Formato de saida:
- Pipelines por estado
- Configs JSON
- Payload publicado
- Benchmark inicial por estado

Definicao de pronto:
- Reducao real de carga (comparado ao baseline monolitico)
- Pipeline contextual funcional
- Sem dependencia direta da UI

Handoff:
- Entregar para RedColorCalibration e TestValidation.
```

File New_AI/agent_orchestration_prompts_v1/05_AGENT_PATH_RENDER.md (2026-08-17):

# Agent_Path_Render

```text
Voce e o agente Agent_Path_Render, com papel de Builder Navigation/UI.

Missao:
Implementar path tracker e render 2D com gradiente, otimizado para execucao prolongada no Pi4.

Escopo permitido:
- Criar `New_AI/obr_overengineering_v1/src/modules/navigation/path_tracker.py`
- Criar `New_AI/obr_overengineering_v1/src/ui_overengineering/components/path_canvas.py`

Escopo proibido:
- Alterar qualquer arquivo fora de `New_AI/obr_overengineering_v1`
- Estrutura sem limite de memoria

Entradas obrigatorias:
- `docs/interfaces.md` (evento nav.pose)
- layout alvo da UI

Passos:
1) Criar deque fixa com `(x,y,theta,timestamp)`.
2) Renderizar trilha com gradiente `#ADD8E6 -> #00008B`.
3) Atualizar a cada 100ms (configuravel).
4) Persistir snapshot JSON rotativo para recovery.

Formato de saida:
- API do tracker
- estrategia de normalizacao
- politica de snapshot

Definicao de pronto:
- Sem overflow de memoria
- Render continuo sem congelar a UI

Handoff:
- Entregar para UIRefactor e TestValidation.
```

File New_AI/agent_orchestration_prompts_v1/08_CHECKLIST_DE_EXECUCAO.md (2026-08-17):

# Checklist rapido para rodar os agentes

1) Envie `00_GLOBAL_PROMPT.md` para todos os agentes.
2) Rode Wave 0 (StateMachine) e valide se `interfaces.md` v1 foi entregue.
3) Rode Wave 1 em paralelo (Vision + UI + Path).
4) Rode Wave 2 em paralelo (Red + ajuste Vision).
5) Rode Wave 3 (TestValidation).
6) Confirme que todos os artefatos estao apenas em `New_AI/obr_overengineering_v1`.
7) Bloqueie merge se testes criticos falharem.

Definition of Done (alinhado ao plano):
- Latencia E2E <= 50ms no cenario de referencia definido.
- Path 2D funcionando com gradiente e sem vazamento de memoria.
- Detector vermelho robusto em condicoes dificeis.
- Logs de transicao FSM aparecendo na UI e no terminal.

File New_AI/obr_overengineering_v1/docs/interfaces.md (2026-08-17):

# Interfaces v1 (Frozen)

Contract scope: `New_AI/obr_overengineering_v1`  
Status: `v1 frozen for Wave 1 integration`  
Owner: `Agent_StateMachine`  
Date: `2026-03-02`

## 1) Official FSM contract

### 1.1 States
- `SEARCHING_LINE`
- `FOLLOWING_LINE`
- `VALIDATING_GAP`
- `CROSSING_GAP`
- `VICTIM_FOUND`
- `RESCUE_ZONE_DETECTED`

### 1.2 Events
- `ON_GAP`
- `ON_LINE_FOUND`
- `ON_LINE_LOST`
- `ON_VICTIM_DETECTED`
- `ON_RESCUE_RED_DETECTED`
- `ON_INTERSECTION`
- `ON_TIMEOUT`
- `ON_RESET`

Legacy event aliases accepted by implementation:
- `ON_VICTIM` -> `ON_VICTIM_DETECTED`
- `ON_INTERSECT` -> `ON_INTERSECTION`
- `ON_RESCUE_RED` -> `ON_RESCUE_RED_DETECTED`

### 1.3 Complete transition table (deterministic)
| Current state | ON_GAP | ON_LINE_FOUND | ON_LINE_LOST | ON_VICTIM_DETECTED | ON_RESCUE_RED_DETECTED | ON_INTERSECTION | ON_TIMEOUT | ON_RESET |
|---|---|---|---|---|---|---|---|---|
| `SEARCHING_LINE` | `SEARCHING_LINE` | `FOLLOWING_LINE` | `SEARCHING_LINE` | `VICTIM_FOUND` | `RESCUE_ZONE_DETECTED` | `SEARCHING_LINE` | `SEARCHING_LINE` | `SEARCHING_LINE` |
| `FOLLOWING_LINE` | `VALIDATING_GAP` | `FOLLOWING_LINE` | `SEARCHING_LINE` | `VICTIM_FOUND` | `RESCUE_ZONE_DETECTED` | `FOLLOWING_LINE` | `SEARCHING_LINE` | `SEARCHING_LINE` |
| `VALIDATING_GAP` | `CROSSING_GAP` | `FOLLOWING_LINE` | `SEARCHING_LINE` | `VICTIM_FOUND` | `RESCUE_ZONE_DETECTED` | `FOLLOWING_LINE` | `SEARCHING_LINE` | `SEARCHING_LINE` |
| `CROSSING_GAP` | `CROSSING_GAP` | `FOLLOWING_LINE` | `CROSSING_GAP` | `VICTIM_FOUND` | `RESCUE_ZONE_DETECTED` | `CROSSING_GAP` | `SEARCHING_LINE` | `SEARCHING_LINE` |
| `VICTIM_FOUND` | `VICTIM_FOUND` | `FOLLOWING_LINE` | `SEARCHING_LINE` | `VICTIM_FOUND` | `RESCUE_ZONE_DETECTED` | `VICTIM_FOUND` | `FOLLOWING_LINE` | `SEARCHING_LINE` |
| `RESCUE_ZONE_DETECTED` | `RESCUE_ZONE_DETECTED` | `FOLLOWING_LINE` | `RESCUE_ZONE_DETECTED` | `VICTIM_FOUND` | `RESCUE_ZONE_DETECTED` | `RESCUE_ZONE_DETECTED` | `FOLLOWING_LINE` | `SEARCHING_LINE` |

Transition log format (mandatory):
- `TIMESTAMP [STATE] msg`
- Example: `2026-03-02T18:52:10.123+00:00 [FOLLOWING_LINE] SEARCHING_LINE --ON_LINE_FOUND--> FOLLOWING_LINE | line detected`

## 2) Official Event Bus topics

| Topic | Payload type | Producer(s) | Consumer(s) |
|---|---|---|---|
| `vision.raw_frame` | `FrameEvent` | Vision Node | UI, Recorder |
| `vision.processed_frame` | `FrameEvent` | Vision Node | UI |
| `vision.detections` | `VisionDetectionEvent` | Vision Node | FSM, UI, Test |
| `fsm.state` | `StateSnapshotEvent` | FSM | Vision, UI, Nav, Test |
| `fsm.transition` | `StateTransitionEvent` | FSM | UI, Logger, Test |
| `nav.pose` | `PoseEvent` | Navigation Node | Path tracker, UI |
| `nav.path` | `PathEvent` | Navigation Node | UI |
| `ui.command` | `UICommandEvent` | UI | Orchestrator, FSM |
| `system.health` | `HealthEvent` | Orchestrator, Perf monitor | UI, Logger, Test |
| `system.log` | `LogEvent` | All nodes | UI, Logger, Test |

## 3) Payload schemas (v1)

### 3.1 BaseEvent
```json
{
  "timestamp": "float (unix seconds)"
}
```

### 3.2 StateTransitionEvent
```json
{
  "timestamp": "float",
  "old_state": "str",
  "new_state": "str",
  "trigger": "str",
  "reason": "str"
}
```

### 3.3 StateSnapshotEvent
```json
{
  "timestamp": "float",
  "state": "str"
}
```

### 3.4 VisionDetectionEvent
```json
{
  "timestamp": "float",
  "state": "str",
  "line": "bool",
  "balls": "int",
  "green": "bool",
  "red": "bool",
  "victims": "int",
  "latency_ms": "float",
  "metadata": "dict[str, any]"
}
```

Additional metadata fields (non-breaking, optional for consumers):
- `silver_ball_found: bool`
- `silver_ball_confidence: float`
- `silver_ball_bbox: {x:int,y:int,w:int,h:int} | null`
- `black_ball_found: bool`
- `black_ball_confidence: float`
- `black_ball_bbox: {x:int,y:int,w:int,h:int} | null`
- `green_corner_found: bool`
- `green_corner_confidence: float`
- `green_corner_bbox: {x:int,y:int,w:int,h:int} | null`
- `red_corner_found: bool`
- `red_corner_confidence: float`
- `red_corner_bbox: {x:int,y:int,w:int,h:int} | null`
- `debug_views_available: list[str]`
- `silver_ball_black_overlap_suppressed: bool`
- `silver_line: {found:bool, confidence:float, bbox:{x:int,y:int,w:int,h:int}|null, mode:str, model:dict, heuristic:dict, decision:dict}`

Important integration rule:
- `VisionDetectionEvent.metadata` must remain JSON-serializable.
- Numpy masks and intermediate frames are exposed only via `VisionNode.get_last_debug_bundle()`, never embedded directly in `vision.detections`.

### 3.5 PoseEvent
```json
{
  "timestamp": "float",
  "x": "float",
  "y": "float",
  "theta": "float"
}
```

### 3.6 PathEvent
```json
{
  "timestamp": "float",
  "poses": "list[PoseEvent]"
}
```

### 3.7 HealthEvent
```json
{
  "timestamp": "float",
  "cpu_percent": "float",
  "fps_capture": "float",
  "fps_process": "float",
  "fps_ui": "float",
  "queue_depth": "int"
}
```

### 3.8 UICommandEvent
```json
{
  "timestamp": "float",
  "command": "str",
  "params": "dict[str, any]"
}
```

### 3.9 FrameEvent
```json
{
  "timestamp": "float",
  "frame_id": "int",
  "width": "int",
  "height": "int",
  "encoding": "str",
  "data": "bytes"
}
```

### 3.10 LogEvent
```json
{
  "timestamp": "float",
  "level": "str",
  "message": "str",
  "source": "str",
  "state": "str"
}
```

## 4) Public APIs frozen in v1
- `EventBus.publish(topic: str, message: BaseEvent) -> None`
- `EventBus.subscribe(topic: str, handler: Callable[[BaseEvent], None]) -> Subscription`
- `StateMachine.handle(event: RobotEvent, payload: dict | None = None) -> RobotState`
- `switch_pipeline(state: RobotState, frame_bgr: np.ndarray, config: VisionConfig) -> VisionDetectionEvent`
- `PathTracker.push(x: float, y: float, theta: float, timestamp: float) -> None`
- `PathTracker.snapshot() -> list[PoseEvent]`

Local-only debug API for calibration/replay:
- `VisionNode.get_last_processed_frame(copy: bool = True) -> np.ndarray | None`
- `VisionNode.get_last_debug_bundle(copy: bool = True) -> dict[str, Any] | None`

`get_last_debug_bundle()` schema:
```json
{
  "frame_id": "int",
  "timestamp": "float",
  "state": "str",
  "metadata": "dict[str, any]",
  "views": "dict[str, np.ndarray]"
}
```

## 5) Error handling and retry rules
- EventBus queue is bounded (`max_queue_size`, default `512`).
- `publish(block=False)` on full queue raises `EventBusFullError` (no silent drop by default).
- Optional policy: instantiate `EventBus(drop_oldest=True)` only for non-critical streams (for example, video frames).
- Subscriber exceptions are isolated; one failing subscriber does not block others.
- Unknown event names in FSM raise `InvalidTransitionError` immediately.
- Recommended retry policy for critical publishers:
  1. Retry up to `3` times.
  2. Backoff `5ms`, `10ms`, `20ms`.
  3. If still failing, emit degraded `system.health` and one `system.log` error.

## 6) Integration notes for builders
- UI should subscribe to: `fsm.state`, `fsm.transition`, `vision.raw_frame`, `vision.processed_frame`, `nav.path`, `system.health`, `system.log`.
- Vision should subscribe to: `fsm.state`; publish `vision.*` only.
- Path module should subscribe to: `nav.pose`; publish `nav.path`.
- TestValidation should assert both `fsm.state` and `fsm.transition` sequences per scenario.

## 7) Handoff
Ready for:
- `Agent_UI_Refactor`
- `Agent_Vision_Optimization`
- `Agent_Path_Render`
- `Agent_RedColorCalibration`
- `Agent_TestValidation`

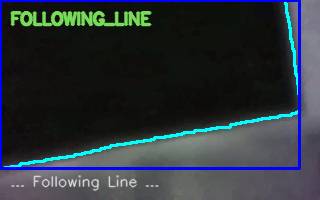
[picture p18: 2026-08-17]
New_AI/obr_overengineering_v1/artifacts/session_analysis/session_20260618_011943_820/t0057.77_processed_processed_003702.jpg

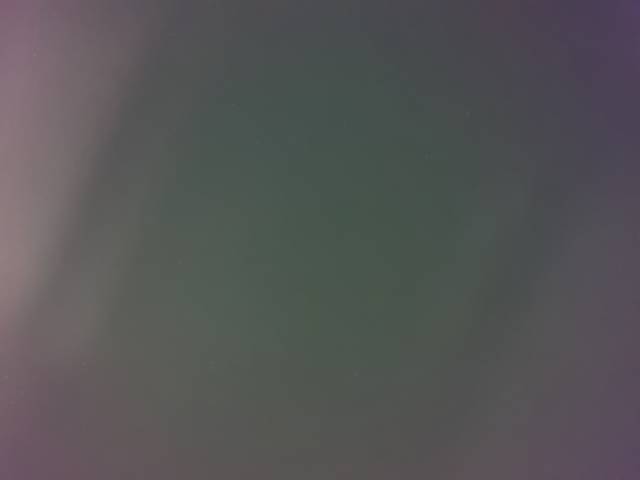
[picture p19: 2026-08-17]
New_AI/obr_overengineering_v1/artifacts/curve_diagnostics_20260812/latest_physical/session_20260618_033042_147/frames/raw_005021.jpg

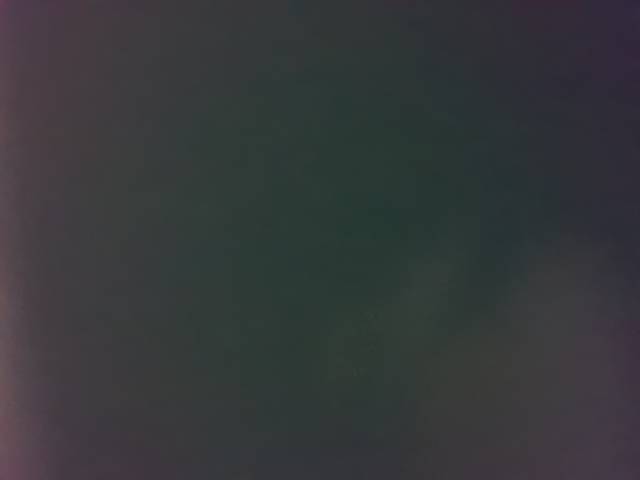
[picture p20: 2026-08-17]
New_AI/obr_overengineering_v1/artifacts/curve_diagnostics_20260812/latest_physical/session_20260618_033042_147/frames/raw_004816.jpg

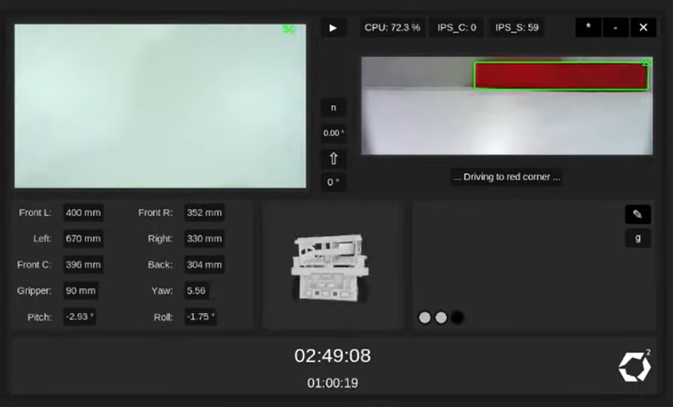
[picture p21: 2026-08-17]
New_AI/Pasta de fotos para inspiração e uso , quero deixar igual/Captura de tela 2026-03-02 151931.png

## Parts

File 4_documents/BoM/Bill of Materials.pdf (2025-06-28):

# | Component | Part name | Author | Source | Quantity | Unit cost (Local Currency) | Unit cost (USA Dollars) | Total Cost (Local Currency) | Total Cost (USA Dollars)

1 | Main processor | Raspberry Pi 4B | Raspberry Pi | PBTech (https://www.pbtech.co.nz/product/SEVRBP0206/Raspberry-Pi-4-Model-B-4GB-LPDDR4-FIRST-28nm-Based) | 1 | 114.88 | 70.0768 | 114.88 | 70.0768
2 | RPi Shield w/ components | Custom | Aidan Zhu | JLCPCB (https://jlcpcb.com/) | 5 | 3.394 | 2.10428 | 16.97 | 10.3517
3 | Colour Sensor Board | Custom | Aidan Zhu | JLCPCB (https://jlcpcb.com/) | 5 | 3.394 | 2.10428 | 16.97 | 10.3517
4 | Heat sink | Raspberry Pi 4 Heatsinks | Raspberry Pi | PBTech (https://www.pbtech.com/product/SEVRBP0049/Raspberry-Pi-Aluminium-Heatsink-Set-for-Raspberry) | 1 | 5.52 | 3.4224 | 5.52 | 3.3672
5 | Filament | PLA Hyper Filament Creality | Creality | PBTech (https://www.pbtech.co.nz/product/INKCRL0013/Creality-Hyper-PLA-Filament-for-High-Speed-3D-Prin) | 2 | 55 | 34.1 | 110 | 67.1
6 | Connecting parts | Screws, Nuts, Washers, Standoffs | Robotics Club | N/A | 0 | 0 | 0 | 0 | 0
7 | Wires | JST, Dupont Sets, Copper Wires | Robotics Club | N/A | 0 | 0 | 0 | 0 | 0
8 | Drive Servos | PDI 6221MG 360 | PDI | Aliexpress (https://www.aliexpress.com/item/1005007751044964.html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) | 4 | 31.12 | 19.2944 | 124.48 | 75.9328
9 | Claw Servo | DSSERVO RDS3218 | DSSERVO | Aliexpress (https://www.aliexpress.com/item/1005007328195711.html) | 1 | 28.65 | 17.763 | 28.65 | 17.4765
10 | IMU | GY-GNO08X | Unknown | Aliexpress (https://www.aliexpress.com/item/1005006995505956.html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) | 1 | 21.95 | 13.609 | 21.95 | 13.3895
11 | Analog I2C Converter | ADS7830 | Adafruit | Adafruit (https://www.adafruit.com/product/5836) | 1 | 9.82 | 6.0884 | 9.82 | 5.9902
12 | Wheels | Silicone Wheels | Unknown | | | | 0 | 0 | 0
13 | Line Follow Camera | Pi Camera Module 3 Wide Angle | Raspberry Pi | PBTech (https://www.pbtech.co.nz/product/SEVRBP0398/Raspberry-Pi-Official-Camera-Module-3-Wide-Version) | 1 | 80.71 | 50.0402 | 80.71 | 49.2331
14 | Close Servo | SG90 | Tower Pro | Jaycar (https://www.jaycar.com.au/arduino-compatible-9g-micro-servo-motor/p/YM2758) | 1 | 11.95 | 7.409 | 11.95 | 7.2895
15 | DC-DC Buck Converter | LM2596S | Unknown | Taobao (https://detail.tmall.com/item.htm?id=597371047995&_u=rf5et8d122) | 1 | 2.83 | 1.7546 | 2.83 | 1.7263
16 | 5V Regulator | MINI560 Pro | Unknown | Aliexpress (https://www.aliexpress.com/item/1005005766969893.html) | 1 | 1.63 | 1.0106 | 1.63 | 0.9943
17 | Totals | | | | | | | 546.36 | 333.2796

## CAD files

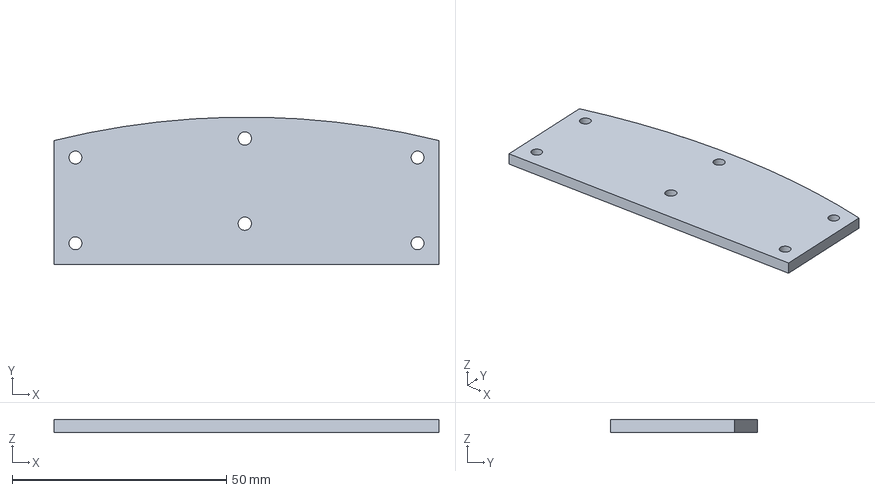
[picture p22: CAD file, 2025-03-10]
3_designs/back_base/Battery Base.step
89.8 x 34.4 x 3.00 mm

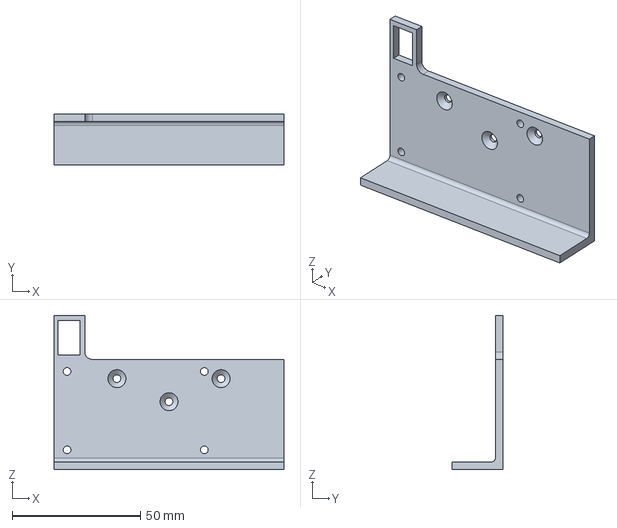
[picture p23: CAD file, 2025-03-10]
3_designs/bottom_base/Bottom Base.step
89.8 x 20.0 x 60.2 mm

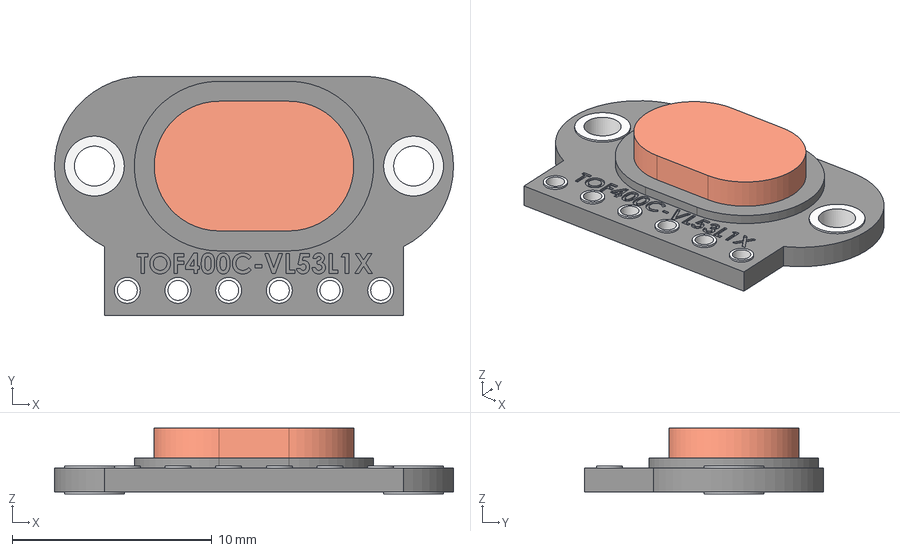
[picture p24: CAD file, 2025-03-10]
3_designs/components/TOF400C.step
20.0 x 12.0 x 3.30 mm

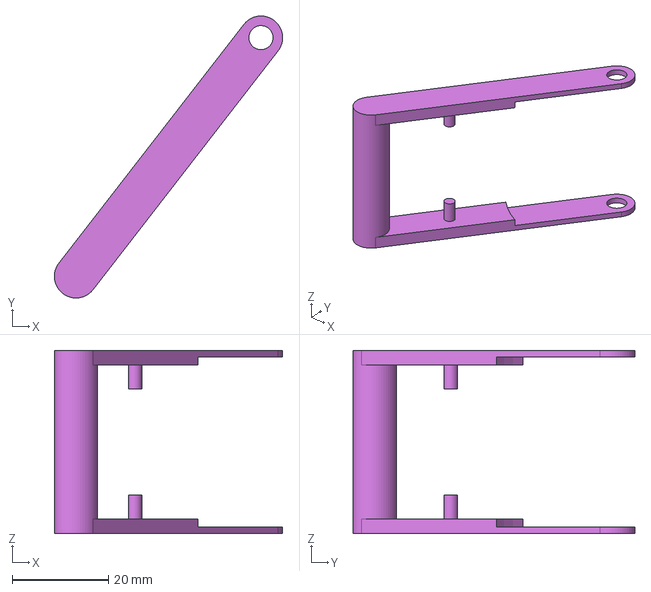
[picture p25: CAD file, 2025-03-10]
3_designs/front_base/claw/Claw - [R] Support.step
47.4 x 58.5 x 38.0 mm

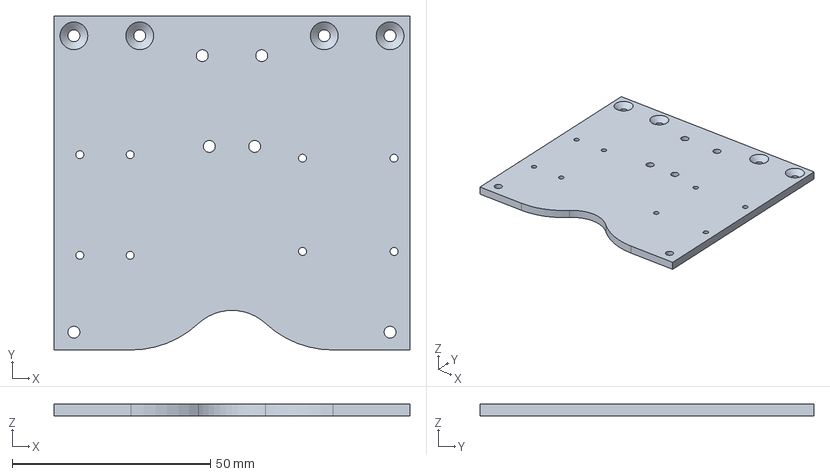
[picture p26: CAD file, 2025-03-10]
3_designs/front_base/Front Base.step
89.8 x 84.3 x 3.00 mm

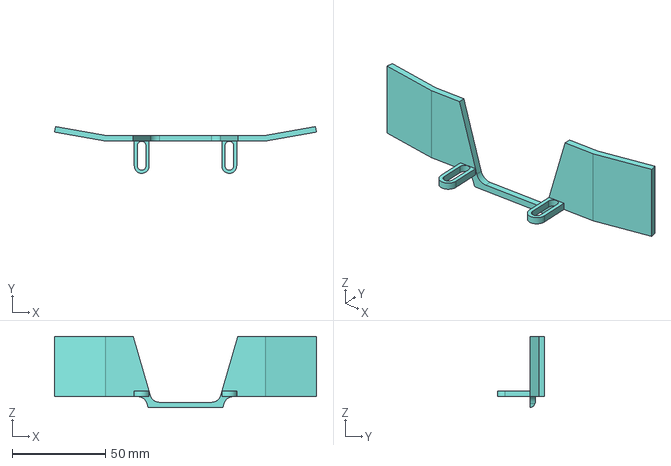
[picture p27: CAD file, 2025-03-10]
3_designs/front_base/lower_parts_frame/Front Touch Plate.step
140.8 x 25.2 x 38.3 mm

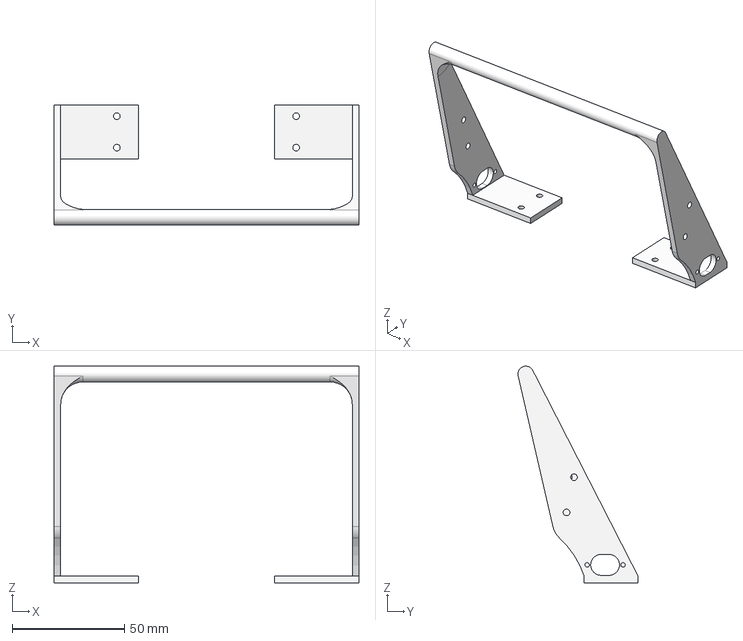
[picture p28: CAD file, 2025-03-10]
3_designs/handle/Handle.step
135.8 x 53.5 x 96.5 mm

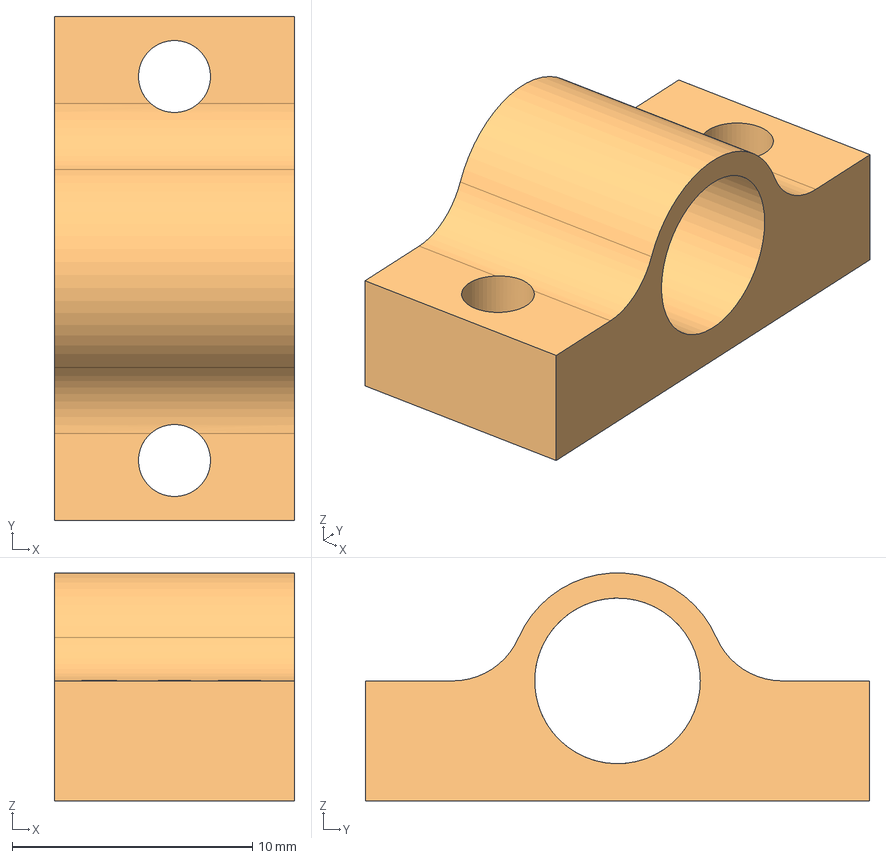
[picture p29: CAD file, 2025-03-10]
3_designs/handle/tilt_holder/Tilt Holder.step
10.0 x 21.0 x 9.49 mm

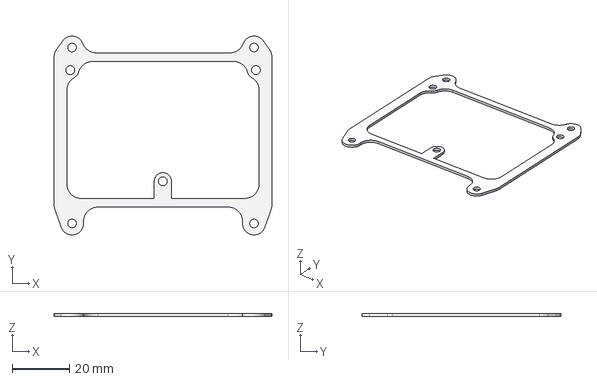
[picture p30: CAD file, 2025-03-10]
3_designs/ir_sensors/IR Sensor Frame.step
76.0 x 69.3 x 1 mm

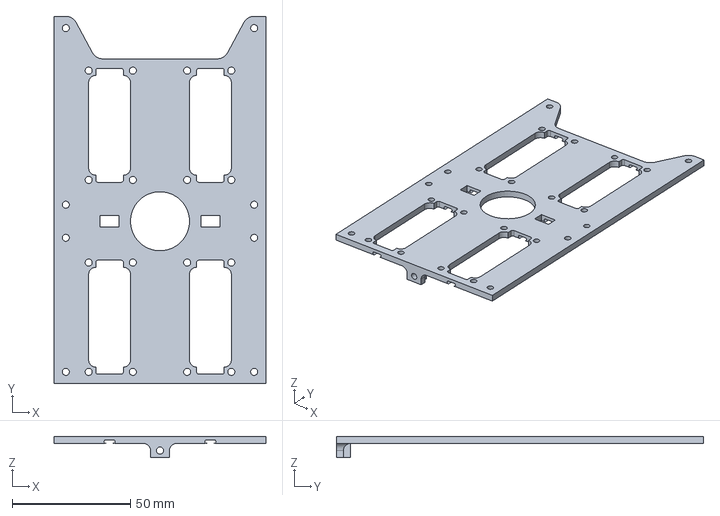
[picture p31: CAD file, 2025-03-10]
3_designs/servos/Servo Base.step
89.8 x 155.6 x 9.00 mm

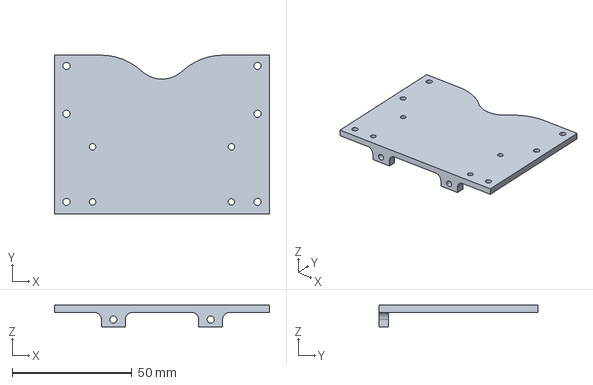
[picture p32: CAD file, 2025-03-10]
3_designs/back_base/Back Base.step
89.8 x 66.3 x 9.00 mm

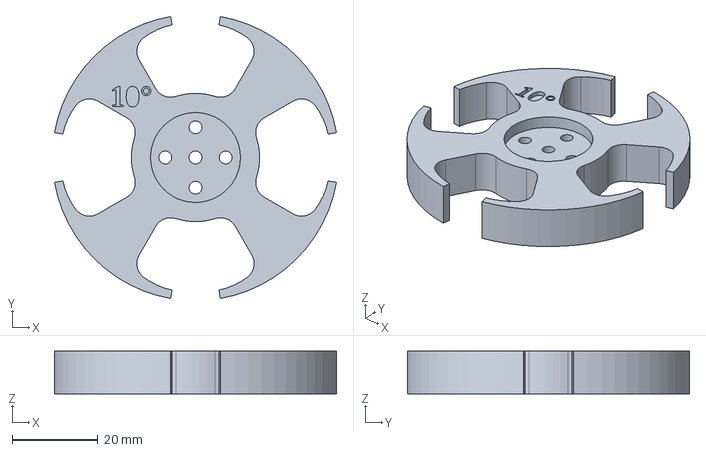
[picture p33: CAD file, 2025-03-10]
3_designs/components/Back Wheg - Back Wheg.step
65.9 x 65.9 x 10.0 mm

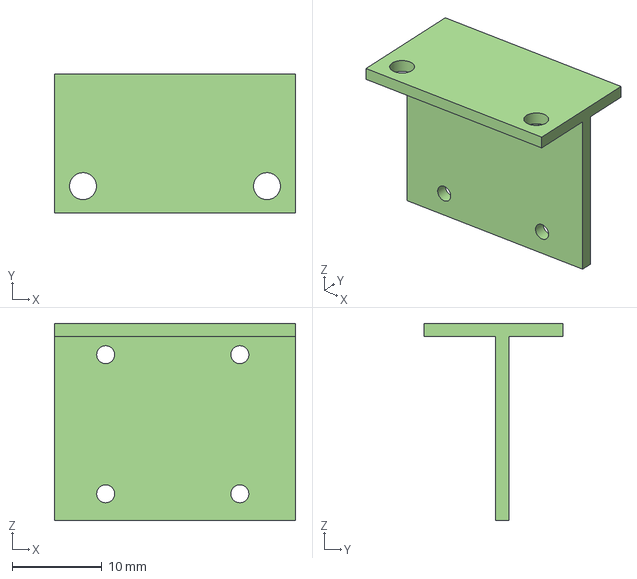
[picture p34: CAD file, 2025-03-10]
3_designs/front_base/BNOO8X Frame.step
26.8 x 15.5 x 22.0 mm

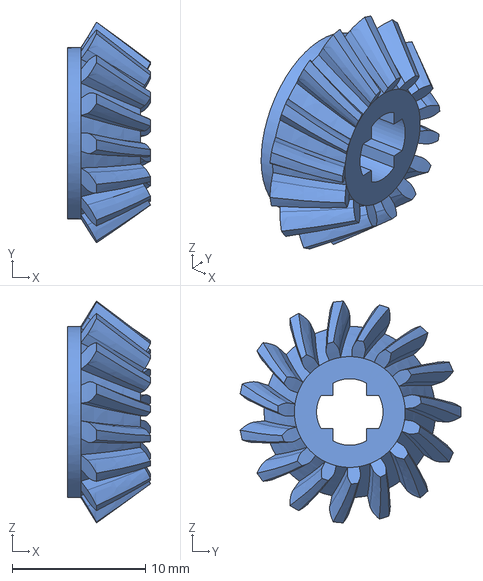
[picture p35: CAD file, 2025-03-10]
3_designs/front_base/claw/Claw - Spiral Bevel 1M 15T 32deg.step
6.23 x 16.6 x 16.7 mm

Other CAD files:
3_designs/front_base/lower_parts_frame/Lower Parts Frame.step
3_designs/servos/Servo Frame.step
3_designs/components/Raspberry Pi Zero 2W Shield.step
3_designs/front_base/claw/Claw - [R] Claw.step
3_designs/components/2 x 18650 Battery Holder.stp
3_designs/components/Claw Servo.step
3_designs/components/Colour Sensor Board.step
3_designs/components/Front Wheg - Front Wheg.step
3_designs/components/OLED 128x64 0.96.step
3_designs/components/PDI_6221MG.STEP
3_designs/components/Rasbperry Pi Camera Module 3.step
3_designs/components/Raspberry Pi Zero 2 W.STEP
3_designs/components/Rocker Switch.stp
3_designs/components/Touch Sensor v1.step
3_designs/front_base/claw/Claw - Drive Servo Frame.step
3_designs/front_base/claw/Claw - Rotating Frame.step
3_designs/front_base/claw/Claw - Spiral Bevel 1M 15T 32deg (1).step
3_designs/front_base/claw/Claw - Spiral Bevel 1M 24T 58deg (1).step
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

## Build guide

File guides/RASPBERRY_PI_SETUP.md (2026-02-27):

# Raspberry Pi 3 Setup Guide (FusionZero IA)

Este guia e para colocar a IA para rodar no Raspberry Pi 3 sem mexer no codigo da IA.
Fluxo completo: resetar SD, instalar sistema, instalar dependencias, testar camera USB e executar.

## 1. Hardware e estrategia com 2 cartoes

- Raspberry Pi 3 Model B/3B+
- 2x microSD 16GB
- 1 camera USB
- Fonte 5V 2.5A ou maior

Use os cartoes assim:

- `SD-A (estavel)`: sistema funcionando para treino/teste rapido.
- `SD-B (laboratorio)`: testes de instalacao e mudancas.

## 2. Melhor sistema para seu caso

Recomendado agora:

- `Raspberry Pi OS Lite (64-bit) - Bookworm`

Motivo:

- suporte atual da Raspberry Pi Foundation
- camera stack moderna (`libcamera`, `picamera2`)
- bom para Pi 3 quando voce quer desempenho e menos consumo de RAM

## 3. Resetar e gravar SD (do zero)

No seu computador:

1. Instale `Raspberry Pi Imager`.
2. Abra o Imager.
3. Escolha `Raspberry Pi OS Lite (64-bit)`.
4. Escolha o cartao SD.
5. Clique na engrenagem (configuracoes avancadas) e preencha:
   - hostname
   - usuario/senha
   - Wi-Fi (SSID/senha)
   - locale/timezone
   - habilitar SSH
6. Grave (`Write`).

Links oficiais:

- Raspberry Pi Downloads: https://www.raspberrypi.com/software/
- Instalar sistema com Raspberry Pi Imager: https://www.raspberrypi.com/documentation/computers/getting-started.html#installing-the-operating-system

## 4. Primeiro boot no Raspberry Pi

Depois de ligar o Pi:

```bash
sudo apt update
sudo apt full-upgrade -y
```

Habilite interfaces e grupos:

```bash
sudo raspi-config
```

No `raspi-config`, habilite o que voce usar:

- Interface Options -> `I2C`
- Interface Options -> `SPI`
- Interface Options -> `SSH` (se ainda nao ativou)

Depois:

```bash
sudo usermod -aG video,gpio,i2c,spi $USER
sudo reboot
```

Link oficial (`raspi-config` e interfaces):

- https://www.raspberrypi.com/documentation/computers/configuration.html

## 5. Pacotes base (sistema)

Depois do reboot:

```bash
sudo apt update
sudo apt install -y \
  git curl wget \
  python3-pip python3-venv python3-dev \
  python3-opencv python3-numpy python3-tk python3-pil \
  python3-picamera2 \
  v4l-utils fswebcam i2c-tools
```

## 6. Trazer o projeto para o Pi

Opcao A (Git):

```bash
cd ~
git clone <URL_DO_REPOSITORIO> FusionZero-Robocup-International
```

Opcao B (copiar do PC via `scp`, no PowerShell do Windows):

```powershell
scp -r "C:\Users\Davib\OneDrive\Área de Trabalho\OBR - Arquivos\FusionZero-Robocup-International" \
<usuario>@<ip-do-pi>:/home/<usuario>/
```

## 7. Ambiente Python (seguro no Bookworm)

No Pi:

```bash
cd ~/FusionZero-Robocup-International
python3 -m venv --system-site-packages .venv
source .venv/bin/activate
python -m pip install --upgrade pip setuptools wheel
```

Instale apenas o que faltar para sua execucao:

```bash
pip install \
  adafruit-blinka \
  adafruit-circuitpython-ads7830 \
  adafruit-circuitpython-vl53l1x \
  adafruit-circuitpython-bno08x \
  adafruit-circuitpython-servokit
```

Observacao importante:

- Nao rode `pip install -r requirements.txt` direto no Pi 3 como primeiro passo.
- Primeiro valide camera + IA base. Depois adicionamos libs extras se necessario.

## 8. Testar camera USB antes da IA

```bash
ls /dev/video*
v4l2-ctl --list-devices
```

Teste captura simples:

```bash
fswebcam -r 640x480 --jpeg 90 test.jpg
ls -lh test.jpg
```

Link oficial de camera no Raspberry Pi (inclui USB webcam):

- https://www.raspberrypi.com/documentation/computers/camera_software.html

## 9. Rodar a IA no Pi 3

Ative o ambiente:

```bash
cd ~/FusionZero-Robocup-International
source .venv/bin/activate
```

Executar UI (com monitor no Pi):

```bash
python pc_vision_ui.py
```

Executar sem UI (mais leve):

```bash
python pc_vision_runner.py --mode all --camera 0
```

Se sua camera USB for outro indice:

```bash
python pc_vision_runner.py --mode all --camera 1
```

## 10. Se der erro de Python/pip no Bookworm

Esse erro e comum no Bookworm:

- `error: externally-managed-environment`

A forma correta e usar `venv` (ja coberto neste guia).

Link oficial:

- https://www.raspberrypi.com/documentation/computers/images.html#using-pip-with-rpi-os

## 11. Opcional: pycoral / tflite (somente se realmente precisar)

Se voce for usar Edge TPU/Coral, instale por `apt` quando possivel (mais estavel no Pi):

```bash
sudo apt update
sudo apt install -y python3-pycoral
```

Referencia oficial do projeto pycoral (recomendacao de `apt`):

- https://github.com/google-coral/pycoral

## 12. Reset rapido (quando quiser voltar do zero)

1. Desligue o Pi.
2. Grave novamente o SD no Raspberry Pi Imager.
3. Repita passos 4 a 9 deste guia.

Com 2 cartoes:

- mantenha `SD-A` sempre funcionando
- use `SD-B` para experimentar

## 13. Checklist final de validacao

Antes de testar IA no tapete:

- `v4l2-ctl --list-devices` mostra a camera USB
- `fswebcam` gera imagem
- `python pc_vision_ui.py` abre
- deteccoes visuais aparecem no preview

---

Quando voce enviar fotos do ponto onde esta, seguimos exatamente o proximo comando.

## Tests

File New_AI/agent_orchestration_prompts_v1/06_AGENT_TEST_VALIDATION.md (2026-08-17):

# Agent_TestValidation

```text
Voce e o agente Agent_TestValidation, com papel de Validator QA.

Missao:
Validar todo o pipeline com testes unitarios/integracao e relatorio de desempenho.

Escopo permitido:
- Criar `New_AI/obr_overengineering_v1/tests/*`
- Criar `New_AI/obr_overengineering_v1/docs/test_report.md`
- Criar `New_AI/obr_overengineering_v1/docs/performance_report.md`

Escopo proibido:
- Alterar qualquer arquivo fora de `New_AI/obr_overengineering_v1`
- Ignorar falhas intermitentes de thread/filas

Entradas obrigatorias:
- `docs/interfaces.md`
- todos os modulos dos agentes

Suite minima:
1) FSM: transicoes validas/invalidas + logs.
2) EventBus: ordem, concorrencia, fila cheia.
3) Vision: switch_pipeline por estado + CLAHE + red detector.
4) UI: nao congelar com eventos continuos; fallback sem camera.
5) E2E: captura -> visao -> fsm -> ui com latencia por etapa.

Formato de saida:
- resultado de testes por arquivo
- regressao por severidade
- relatorio de latencia e estabilidade

Definicao de pronto:
- testes criticos verdes
- riscos residuais documentados

Handoff:
- Entrega final consolidada.
```

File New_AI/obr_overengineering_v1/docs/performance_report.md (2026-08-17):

# Performance and Stability Report - Agent_TestValidation

Date: 2026-03-03  
Scope: `New_AI/obr_overengineering_v1`

## Method

- Functional/perf validation suite:
  - `python -m pytest New_AI/obr_overengineering_v1/tests -q`
- Stage-latency probe:
  - Synthetic capture frames through `VisionNode` + `StateMachine` + EventBus subscribers representing UI ingestion.
  - 45 frames, bounded queue (`max_queue_size=2048`, `drop_oldest=False`).

## Latency by stage

| Stage | Avg (ms) | P95 (ms) |
|---|---:|---:|
| Capture -> Vision call return | 39.073 | 60.296 |
| Capture -> Detection dispatch | 39.413 | 60.716 |
| Vision detection -> FSM transition | 0.509 | 0.726 |
| FSM transition -> UI state subscriber | 0.037 | 0.055 |
| End-to-end (Capture -> UI state) | 39.959 | 61.436 |

## Stability signals

- Frames requested: `45`
- Samples matched across all stages: `45`
- Lost samples: `0`
- EventBus concurrency test: `4 publishers x 120 messages`, no message loss (`480/480` received).
- Queue backpressure behavior:
  - Without `drop_oldest`: queue-full errors observed as expected.
  - With `drop_oldest=True`: no queue-full error observed under same stress pattern.

## Interpretation

- Pipeline stage timing is stable under synthetic load, with low dispersion and ~61 ms P95 end-to-end in this desktop execution profile.
- EventBus queue policy behaves deterministically for both strict and lossy modes.
- No intermittent thread/queue failures were observed in executed tests.
- UI stress/corner/steering/no-camera tests execute with `PyQt6` installed and pass (`4/4`).

## Residual performance risks

- Numbers are synthetic and desktop-runner based; they are not direct Raspberry Pi 4 hardware measurements.
- Model-backed branches (real silver/dead victim inference) were not profiled with production model execution in this pass.

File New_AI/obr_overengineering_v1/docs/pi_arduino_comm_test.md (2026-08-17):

# Teste Rapido Pi <-> Arduino <-> Dashboard

## Objetivo desta fase

Esta etapa nao e o robo final completo. O foco agora e validar:

- Raspberry Pi vendo a pista com a camera USB
- Raspberry Pi enviando assistencias seriais para o Arduino Mega
- Arduino Mega controlando o L298N e os motores
- PC acompanhando tudo pelo dashboard remoto simples

Nesta fase o firmware do Mega esta em `camera_assist_only=true`.
Isso significa:

- os sensores locais de linha `A0-A4` ficam ignorados
- a linha vem da camera no Raspberry
- `ASST LINE`, `ASST GREEN` e `ASST OBSTACLE` sao a fonte principal de decisao

## Pinagem final usada no Mega

L298N -> Arduino Mega

- `ENA -> D2`
- `IN1 -> D4`
- `IN2 -> D8`
- `IN3 -> D3`
- `IN4 -> D5`
- `ENB -> D7`

Motores no L298N:

- `OUT1/OUT2 -> motor esquerdo`
- `OUT3/OUT4 -> motor direito`

Observacoes:

- o canal A do L298N virou o motor esquerdo
- o canal B do L298N virou o motor direito
- se o robo andar para tras ou girar invertido, ajuste primeiro:
  - `LEFT_MOTOR_INVERTED`
  - `RIGHT_MOTOR_INVERTED`
- nao troque a pinagem antes de testar essas flags

## Arquivos principais desta fase

- firmware Mega:
  - `New_AI/obr_overengineering_v1/arduino/fusionzero_line_follower_controller/fusionzero_line_follower_controller.ino`
- runner no Pi:
  - `New_AI/obr_overengineering_v1/scripts/run_pi_comm_test.sh`
- dashboard simples no PC:
  - `New_AI/obr_overengineering_v1/scripts/run_pc_comm_dashboard.ps1`
- smoke test serial:
  - `New_AI/obr_overengineering_v1/scripts/robot_serial_smoke_test.py`

## O que fica conectado em cada momento

### 1. Upload inicial do firmware

Use o PC ligado por USB no Mega.

Nessa hora:

- PC -> USB -> Arduino Mega
- Raspberry ainda nao precisa estar ligado
- motores e camera podem ficar desligados

### 2. Teste real de comunicacao

Depois do upload, retire o USB do PC e passe o Mega para o Raspberry.

Nessa hora:

- Raspberry Pi -> USB -> Arduino Mega
- camera USB -> Raspberry Pi
- bateria dos motores -> L298N
- PC fica solto, sem cabo no robo
- PC so precisa estar na mesma rede do Raspberry

Resumo importante:

- o PC nao precisa ficar plugado no robo para o teste real
- o PC so abre o dashboard remoto
- quem manda no robo durante o teste e o conjunto Raspberry + Arduino

## Ordem recomendada de preparacao

### A. Preparar no PC

1. Atualize os arquivos do projeto no seu PC.
2. Grave o sketch no Mega.
3. Se quiser, rode o smoke test serial com o Mega ainda no PC.

Exemplo de smoke test:

```powershell
python .\New_AI\obr_overengineering_v1\scripts\robot_serial_smoke_test.py --port COM5
```

O esperado no minimo e:

- `READY FUSIONZERO`
- `PONG`
- `ACK ASST LINE`
- `ACK ASST GREEN`
- `ACK ASST OBSTACLE`
- `ACK STOP`

### B. Levar para o Raspberry por microSD

Se voce vai usar o microSD no lugar de SSH:

1. Desligue o Raspberry.
2. Tire o microSD.
3. Plugue o microSD no PC.
4. Copie a pasta atualizada `New_AI/obr_overengineering_v1` para o sistema de arquivos do Pi.
5. Recoloque o microSD no Raspberry.

Dica pratica:

- se a maioria dos arquivos ja esta no Pi, copie pelo menos:
  - `src/`
  - `scripts/`
  - `docs/`
  - `arduino/`
  - `deploy/fusionzero.env.example` ou seu `fusionzero.env`

### C. Subir o Pi para o teste real

No Raspberry, use o runner dedicado desta fase:

```bash
bash New_AI/obr_overengineering_v1/scripts/run_pi_comm_test.sh
```

Defaults importantes desse script:

- camera USB em `camera-index=0`
- serial do Mega em `/dev/ttyACM0`
- baud `115200`
- profile `pi3_field`
- relay remoto na porta `8765`

Se precisar mudar a serial:

```bash
FZ_ROBOT_SERIAL_PORT=/dev/ttyACM1 bash New_AI/obr_overengineering_v1/scripts/run_pi_comm_test.sh
```

## Abrindo o dashboard no PC

Com o Raspberry e o PC na mesma rede:

```powershell
powershell -ExecutionPolicy Bypass -File .\New_AI\obr_overengineering_v1\scripts\run_pc_comm_dashboard.ps1 -Host <IP_DO_RASPBERRY>
```

O dashboard simples mostra:

- `Pi relay`
- `Arduino serial`
- `Heartbeat`
- video processado
- visao:
  - `line`
  - `green`
  - `green_instruction`
  - `line_offset_norm`
  - `line_angle_deg`
- telemetria:
  - `mode`
  - `assist_kind`
  - `line_error`
  - `pid_output`
  - `green_instruction`
  - `obstacle_state`
  - `failsafe`
- badges:
  - `linha detectada`
  - `assistencia LINE enviada`
  - `duplo verde -> VERDE_MEIA_VOLTA`
  - `Arduino em GREEN`
  - `failsafe ativo`

Comandos disponiveis no dashboard:

- `Forward test`
- `STOP`
- `ESTOP`
- `Clear ESTOP`
- `Obstacle test`
- `Clear obstacle`

## Sequencia de teste recomendada

### Teste 1. Link basico

- ligue Pi + Mega
- abra o dashboard no PC
- confirme:
  - `Pi relay = CONNECTED`
  - `Arduino serial = CONNECTED`
  - `Heartbeat = OK`

### Teste 2. Comando manual

- clique `Forward test`
- confirme no dashboard que a serial continua viva
- clique `STOP`

### Teste 3. Linha preta

- posicione a camera para enxergar a linha preta
- confirme:
  - `line = YES`
  - badge `linha detectada`
  - badge `assistencia LINE enviada`
  - `assist_kind = LINE`
  - `mode = FOLLOW_LINE` no Arduino

### Teste 4. Dois verdes

- mostre os dois quadrados verdes para a camera
- confirme:
  - `green = YES`
  - `green_instruction = VERDE_MEIA_VOLTA`
  - badge `duplo verde -> VERDE_MEIA_VOLTA`
  - `mode = GREEN`

O esperado e o Mega executar a meia-volta de 180 graus.

### Teste 5. Fail-safe

- desconecte a serial ou derrube o link Pi↔Mega
- confirme:
  - estado serial fica stale / erro
  - badge `failsafe ativo`
  - motores param

## Alimentacao e cabos

Para o teste real:

- Mega pode receber logica pela USB do Raspberry
- motores devem ficar na bateria do robo via L298N
- mantenha GND comum entre os modulos de controle e potencia

## Quando mexer no codigo de novo

So mexa antes do proximo teste se acontecer um destes casos:

- motor esquerdo ou direito invertido
- serial do Mega apareceu em outra porta
- camera USB entrou em outro indice
- o Raspberry abre o runner, mas o dashboard nao conecta por IP/rede

Se aparecer qualquer duvida sobre eletrica restante, alimentacao ou indices reais de porta no Pi, vale me passar isso antes de ligar tudo no chao para o primeiro teste.

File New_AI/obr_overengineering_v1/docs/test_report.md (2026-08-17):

# Test Report - Agent E Integration

Date: 2026-03-09  
Scope: `New_AI/obr_overengineering_v1/tests/*`

## Summary

- Compile check:
  - `python -m compileall New_AI/obr_overengineering_v1/src New_AI/obr_overengineering_v1/tests`
  - result: success
- Full suite:
  - `python -m pytest -p no:cacheprovider --basetemp C:\Users\Davib\AppData\Local\FusionZero\venvs\obr_overengineering_v1-pc\pytest_tmp_<timestamp> New_AI/obr_overengineering_v1/tests -q`
  - result: `116 passed in 11.61s`

## Integration fixes verified

- Remote dashboard snapshot replay now delivers the pre-connect log snapshot before the server emits its own connect log.
- Session recorder keeps profile-provided recording settings when UI commands send partial overrides.
- Silver-line heuristic uses a stable pre-enhancement frame path and adaptive specular gating, restoring the offline detection and replay workflows.
- Dashboard robot controls are wired to the headless runner command channel and covered by UI tests.
- Windows PC bootstrap now installs into a short venv path that avoids PyQt wheel extraction failures on deep OneDrive paths.

## Suites covered by the full run

- FSM transitions and guardrails
- Event bus ordering and backpressure
- Remote dashboard server/client replay and reconnect flow
- Live dashboard runner safety/profile/session wiring
- Serial robot adapter command/ACK behavior
- Session recording and sample export
- UI dashboard behavior and robot command publishing
- Vision preprocessing, detectors, offline replay, and dataset export
- End-to-end capture -> vision -> FSM -> UI pipeline

## Environment notes

- On this Windows workspace, `pytest` temporary directories are only stable when `--basetemp` points to the short venv path under `%LOCALAPPDATA%`.
- Default temp paths under the OneDrive workspace produced `PermissionError` during pytest tmpdir cleanup; this was an environment issue, not a code regression.

## Residual risks

- Validation is fully green in the desktop environment, but Raspberry Pi 3 hardware-in-the-loop validation is still required for camera timing, serial latency, and Wi-Fi stability.
- `silver_line` model loading still depends on the deployed model artifact; the heuristic fallback is validated, but field calibration may still need tuning.

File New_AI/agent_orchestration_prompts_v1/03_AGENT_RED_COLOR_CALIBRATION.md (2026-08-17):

# Agent_RedColorCalibration

```text
Voce e o agente Agent_RedColorCalibration, com papel de Specialist Vision.

Missao:
Implementar detector robusto de vermelho com dupla mascara HSV e classificacao de contexto.

Escopo permitido:
- Criar `New_AI/obr_overengineering_v1/src/modules/vision/red_detector.py`
- Criar `New_AI/obr_overengineering_v1/configs/hsv_red.json`

Escopo proibido:
- Alterar qualquer arquivo fora de `New_AI/obr_overengineering_v1`
- Hardcode sem config externa

Entradas obrigatorias:
- `docs/interfaces.md`
- Logica atual de vermelho em `pc_vision_runner.py`

Especificacao obrigatoria:
- Lower1: (0,100,100), Upper1: (10,255,255)
- Lower2: (160,100,100), Upper2: (180,255,255)
- `mask = cv2.bitwise_or(mask1, mask2)`

Passos:
1) Implementar dupla mascara + limpeza morfologica configuravel.
2) Implementar `identify_red_context(contour)` com:
   - aspect ratio
   - convexity defects
   - fallback: solidity/extent
3) Classificar: `red_line_finish`, `rescue_zone_border`, `unknown_red`.

Formato de saida:
- API do red detector
- JSON de configuracao
- thresholds sugeridos

Definicao de pronto:
- Diferenciar faixa vermelha de zona de resgate em cenarios comuns
- Parametros tunaveis sem alterar codigo

Handoff:
- Entregar para VisionOptimization e TestValidation.
```

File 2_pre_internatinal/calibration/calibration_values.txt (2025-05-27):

7.10 9.03 13.09 22.48 63.92 -56.28 -21.35 -12.75 -8.91 -6.70 
6.20 7.94 10.47 16.92 40.13 -55.05 -19.02 -11.42 -8.26 -6.29 
5.09 6.59 9.15 15.34 50.86 -47.73 -15.12 -9.03 -8.37 -6.10 
5.44 6.79 9.61 15.71 44.90 -50.69 -16.37 -9.78 -7.00 -5.43

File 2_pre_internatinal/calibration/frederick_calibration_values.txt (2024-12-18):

4.68 6.06 8.71 15.39 64.80 40.01 12.82 7.54 5.55 4.59
4.97 5.86 8.33 14.46 47.65 67.51 14.04 8.03 5.51 4.56
4.91 5.96 8.39 14.33 47.99 39.45 13.11 8.05 5.84 4.89
4.88 5.77 8.28 14.11 46.50 45.11 13.10 7.96 5.76 4.85

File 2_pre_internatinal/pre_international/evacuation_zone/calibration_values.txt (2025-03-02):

23,25,35,27,23,119,115
163,164,163,181,185,206,214

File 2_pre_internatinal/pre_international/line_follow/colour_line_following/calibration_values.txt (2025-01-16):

44,44,72,55,58,167,154
207,208,221,148,196,227,226

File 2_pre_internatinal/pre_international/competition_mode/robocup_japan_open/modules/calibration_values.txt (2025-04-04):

39,42,40,39,29,102,89
167,163,153,151,150,190,181

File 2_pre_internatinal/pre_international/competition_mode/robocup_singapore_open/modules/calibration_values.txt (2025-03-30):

25,27,25,19,17,98,78
184,178,168,166,164,193,177

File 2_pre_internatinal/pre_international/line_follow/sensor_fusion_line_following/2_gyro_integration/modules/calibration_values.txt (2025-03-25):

27,31,35,24,16,89,67
187,182,177,167,164,171,156

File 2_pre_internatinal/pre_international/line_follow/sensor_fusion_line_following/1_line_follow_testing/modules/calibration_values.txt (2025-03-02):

45,54,0,50,36,143,143
196,192,196,213,208,211,219

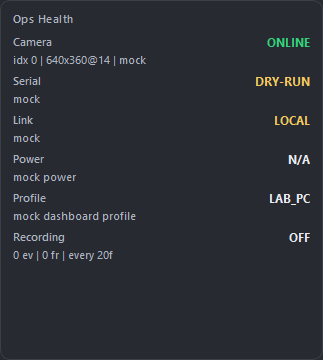
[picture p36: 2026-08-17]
New_AI/obr_overengineering_v1/artifacts/debug_ui/ops_health_maximized_verified.png

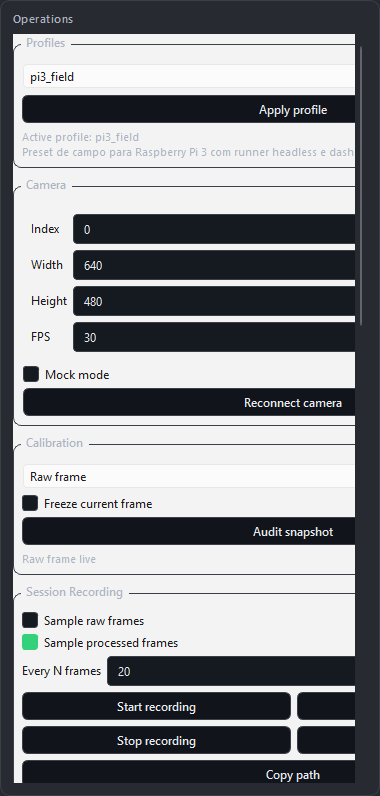
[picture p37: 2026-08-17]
New_AI/obr_overengineering_v1/artifacts/debug_ui/tuning_current.png

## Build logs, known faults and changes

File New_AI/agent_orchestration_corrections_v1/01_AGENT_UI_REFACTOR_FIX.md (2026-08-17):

# Prompt de Correção Pós-Implementação: Interface Gráfica

**Agente Responsável:** `Agent_UI_Refactor`
**Modo Ativo:** Debug & Fix
**Arquivos Alvo:** `src/ui_overengineering/dashboard.py` (ou arquivo equivalente contendo o loop principal PyQt6/Tkinter).

## Problema Identificado (O Gargalo)

O Dashboard recém implementado está sofrendo de frame-drops severos e está congelando a Main Thread. Além disso, o status textual da Máquina de Estados ("... Following Line ...") não está mudando de forma reativa aos eventos do robô.

## Tarefa de Correção

> ATUAÇÃO: Agent_UI_Refactor. MODO: Debug & Fix.
> TAREFA: O Dashboard recém implementado em PyQt6 está sofrendo de frame-drops e congelando a Main Thread. Você deve refatorar o loop de atualização de imagens (`update_frame`).
>
> 1. Converta a emissão do Frame pelo módulo de Visão em um `pyqtSignal(np.ndarray)` assíncrono.
> 2. As imagens recebidas devem ser redimensionadas (`cv2.resize`) em uma QThread separada ANTES de serem enviadas ao `QLabel` principal via `QPixmap`.
> 3. Na barra central-superior de eventos FSM, garanta que ela possui um Observer local conectado ao `Event_Bus` via um `pyqtSlot` (Slot-Signal Qt puro), para alterar o texto instantaneamente de "... Following Line ..." para "... Picking up alive victim ...".

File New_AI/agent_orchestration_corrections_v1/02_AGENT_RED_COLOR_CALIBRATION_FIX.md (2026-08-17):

# Prompt de Correção Pós-Implementação: Calibração de Vermelho

**Agente Responsável:** `Agent_RedColorCalibration`
**Modo Ativo:** Debug & Fix
**Arquivos Alvo:** Processador de Visão / Pipeline de detecção Vermelha.

## Problema Identificado (Falsos Positivos)

O filtro vermelho está detectando tons terrosos, madeira (parede) ou objetos laranjas sob reflexão. Formas não retangulares estão sendo aceitas como interseção da última linha da pista.

## Tarefa de Correção

> ATUAÇÃO: Agent_RedColorCalibration. MODO: Debug & Fix.
> TAREFA: A detecção dupla de HSV implementada está com range muito flexível. Aplique uma restrição aguda: O range inferior deve ir de [0, 150, 100] a [8, 255, 255] e o range superior de [170, 150, 100] a [180, 255, 255]. Aumente drasticamente a exigência mínima de Saturação (S) para matar laranjas e marrons. Além disso, reforce a função de `identify_red_context`: Injete validação de polinômio `cv2.approxPolyDP`. Se for a linha vermelha da pista, o bounding box DEVE ser estreito e longo. Se for sala de resgate, DEVE ser um mancha disforme vasta ou contorno côncavo. Expurga contornos abaixo de 500 pixels de Área (`cv2.contourArea`).

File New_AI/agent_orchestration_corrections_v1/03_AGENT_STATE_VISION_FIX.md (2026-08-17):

# Prompt de Correção Pós-Implementação: Otimização Condicional e FSM

**Agentes Responsáveis:** `Agent_StateMachine` & `Agent_Vision_Optimization`
**Modo Ativo:** Debug & Integration Fix
**Arquivos Alvo:** `src/core/state_machine.py` e `src/modules/vision/pipelines.py`

## Problema Identificado (O Gargalo de Processamento)

A YOLO (ou outro modelo pesado de segmentação/detecção de círculos) continua rodando a todo instante, até mesmo quando o robô está apenas seguindo linha de forma segura. Isso está drenando os recursos ($CPU/GPU$) da Raspberry Pi / Computador Embarcado.

## Tarefa de Correção

> ATUAÇÃO: Agent_Vision_Optimization e Agent_StateMachine. MODO: Debug & Integration Fix.
> TAREFA: A arquitetura atual de FSM não está cortando funções pesadas dinamicamente. Refatore `vision/pipelines.py` injetando uma leitura rigorosa do evento (getter) `current_state()` da Máquina de Estados.
>
> **Regra Absoluta:**
>
> - Se `estado == SEARCHING_LINE` ou `FOLLOWING_LINE` ou `VALIDATING_GAP` -> RETORNE IMEDIATAMENTE (Return early) na função _antes_ de carregar o modelo neural de resgate (YOLO/HoughCircles). Apenas rode Binarização Preta para detecção de linha.
> - Se `estado == RESCUE_ZONE_DETECTED` -> Desative a máscara de linha negra (Binarização), e aloque 100% dos recursos visuais no tracking de Vitimas Vivas (Prata) e Mortas (Preta).
>
> Mande que a mudança severa de pipeline de processamento da matriz de imagem dispare um Log robusto (`[INFO] CV_PIPELINE SWITCHED TO RESCUE_ZONE`) demonstrando a economia de pipeline no buffer.

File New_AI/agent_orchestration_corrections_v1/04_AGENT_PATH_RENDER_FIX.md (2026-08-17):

# Prompt de Correção Pós-Implementação: Estouro de Memória do Path

**Agente Responsável:** `Agent_Path_Render`
**Modo Ativo:** Debug & Fix
**Arquivos Alvo:** `src/ui_overengineering/components/path_canvas.py` (ou componente que controla o 2D Plot das Rodas).

## Problema Identificado (Memory Leak)

Após rodadas longas simuladas ou na competição (acima de 3-4 minutos), o histórico de posições preenche indefinidamente o Canvas e Arrays, derrubando a interface Qt ou PyGame e travando toda a memória da placa (OOM/Buffer Overflow).

## Tarefa de Correção

> ATUAÇÃO: Agent_Path_Render. MODO: Debug & Fix.
> TAREFA: Refatorar o componente renderizador do caminho (Path 2D). Você não pode permitir o uso de Lists puras (`[]`) crescendo infinitamente para armazenar coordenadas (X, Y).
>
> 1. Troque o array infinito por um buffer rotatório estático importando `collections.deque(maxlen=1000)` ou tamanho que julgar estável para UI.
> 2. Se o robô ficar bloqueado/parado na pista (Ex: `Distância entre nova coordenada e coordenada[-1] < 1 pixel`), NÃO a adicione na `deque` (Implemente um cálculo rápido de Distância Euclidiana antes do `.append()`).
> 3. No loop de renderização (PaintEvent), desenhe apenas os segmentos de linha unidos de uma vez no `QPainter` a partir desse Deque estático, mitigando 100% de memory leak de desenho por retenção indiscriminada.

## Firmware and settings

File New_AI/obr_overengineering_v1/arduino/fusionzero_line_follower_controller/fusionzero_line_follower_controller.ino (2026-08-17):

/*
  FusionZero line follower controller (Arduino main motion brain)

  Responsibilities:
    - read line sensors at deterministic rate
    - run local PID + heading stabilization
    - control motors
    - keep a watchdog against Raspberry/serial loss
    - accept only high-level assists from Raspberry Pi

  Supported protocol:
    PING
    CMD FORWARD <duration_ms>
    CMD STOP 0
    CMD ESTOP 0
    CMD RESET_ESTOP 0
    ASST LINE found=<0|1> offset=<float> angle=<float> conf=<float> gap=<int> source=<token>
    ASST GREEN found=<0|1> instruction=<VERDE_ANTES|VERDE_DEPOIS|VERDE_MEIA_VOLTA> side=<LEFT|RIGHT|BOTH> conf=<float> hold_ms=<int> source=<token>
    ASST OBSTACLE state=<CLEAR|AHEAD|TEST> conf=<float> hold_ms=<int> source=<token>

  Responses:
    READY FUSIONZERO
    PONG
    ACK FORWARD <duration_ms>
    ACK STOP
    ACK ESTOP
    ACK RESET_ESTOP
    ACK ASST LINE
    ACK ASST GREEN
    ACK ASST OBSTACLE
    ERR <reason>
    EVENT WATCHDOG_STOP
    TLM ...

  Hardware gaps intentionally left configurable:
    - IMU reading is a stub until the real gyro is wired
    - local color sensor hook is a stub until the real sensor is wired
    - front obstacle sensors are optional and can be disabled with pin = -1
*/

#include <string.h>

const long SERIAL_BAUD = 115200;
const unsigned long CONTROL_PERIOD_MS = 10;
const unsigned long TELEMETRY_PERIOD_MS = 100;
const unsigned long HEARTBEAT_TIMEOUT_MS = 1400;
const unsigned long LINE_ASSIST_VALID_MS = 450;

const int LEFT_PWM_PIN = 2;
const int LEFT_IN1_PIN = 4;
const int LEFT_IN2_PIN = 8;
const int RIGHT_PWM_PIN = 7;
const int RIGHT_IN1_PIN = 3;
const int RIGHT_IN2_PIN = 5;

// Flip these on the first bench test if a track spins backwards.
const bool LEFT_MOTOR_INVERTED = false;
const bool RIGHT_MOTOR_INVERTED = true;
const bool CAMERA_ASSIST_ONLY_MODE = true;

const int LINE_SENSOR_COUNT = 5;
const int LINE_SENSOR_PINS[LINE_SENSOR_COUNT] = {A0, A1, A2, A3, A4};
const float LINE_SENSOR_WEIGHTS[LINE_SENSOR_COUNT] = {-1.0f, -0.5f, 0.0f, 0.5f, 1.0f};
const int LINE_SENSOR_CAL_MIN[LINE_SENSOR_COUNT] = {140, 140, 140, 140, 140};
const int LINE_SENSOR_CAL_MAX[LINE_SENSOR_COUNT] = {900, 900, 900, 900, 900};
const bool LINE_BLACK_IS_LOW = true;
const float LINE_ACTIVE_THRESHOLD = 0.34f;

const int FRONT_SENSOR_PIN = -1;
const int FRONT_LEFT_SENSOR_PIN = -1;
const int FRONT_RIGHT_SENSOR_PIN = -1;
const bool FRONT_SENSOR_ACTIVE_LOW = true;

const bool GYRO_ENABLED = false;
const bool LOCAL_COLOR_SENSOR_ENABLED = false;

struct PIDConfig {
  float kp;
  float ki;
  float kd;
  float smoothingAlpha;
  float integralLimit;
  float derivativeLimit;
  float maxTurn;
  float headingKp;
};

struct SpeedConfig {
  int straight;
  int medium;
  int curve;
  int cautious;
  int reverse;
  int turn;
};

struct PIDRuntime {
  float filteredError;
  float lastFilteredError;
  float integral;
  float derivative;
  float output;
};

struct LineReading {
  bool found;
  float error;
  float confidence;
  int activeCount;
};

struct ObstacleReading {
  bool frontBlocked;
  bool leftBlocked;
  bool rightBlocked;
  int frontMm;
  int leftMm;
  int rightMm;
};

struct LineAssist {
  bool valid;
  bool found;
  float offsetNorm;
  float angleDeg;
  float confidence;
  int gapFrames;
  unsigned long expiresAtMs;
};

struct GreenAssist {
  bool active;
  char instruction[20];
  char side[12];
  float confidence;
  unsigned long expiresAtMs;
};

struct ObstacleAssist {
  bool active;
  char state[12];
  float confidence;
  unsigned long expiresAtMs;
};

enum ControlMode {
  MODE_SAFE_STOP = 0,
  MODE_FOLLOW_LINE = 1,
  MODE_GREEN_MANEUVER = 2,
  MODE_OBSTACLE_AVOID = 3,
  MODE_MANUAL_FORWARD = 4,
  MODE_ESTOP = 5
};

PIDConfig pidCfg = {1.45f, 0.18f, 0.42f, 0.45f, 0.70f, 2.40f, 145.0f, 18.0f};
SpeedConfig speedCfg = {165, 140, 115, 95, 85, 120};
PIDRuntime pidState = {0.0f, 0.0f, 0.0f, 0.0f, 0.0f};
LineAssist lineAssist = {false, false, 0.0f, 90.0f, 0.0f, 0, 0};
GreenAssist greenAssist = {false, "NO_GREEN", "NONE", 0.0f, 0};
ObstacleAssist obstacleAssist = {false, "CLEAR", 0.0f, 0};

String lineBuffer;
unsigned long lastControlAtMs = 0;
unsigned long lastTelemetryAtMs = 0;
unsigned long lastHeartbeatAtMs = 0;
unsigned long manualForwardUntilMs = 0;
unsigned long maneuverStartedAtMs = 0;
unsigned long obstacleStartedAtMs = 0;
bool estopLatched = false;
bool watchdogEventSent = false;
bool failsafeSerialLoss = false;

ControlMode currentMode = MODE_SAFE_STOP;
int lastLeftPwm = 0;
int lastRightPwm = 0;
LineReading lastLine = {false, 0.0f, 0.0f, 0};
ObstacleReading lastObstacle = {false, false, false, 1200, 1200, 1200};

float fAbs(float value);
float clampFloat(float value, float low, float high);
float normalizeLineSensor(int rawValue, int minValue, int maxValue);
LineReading readLineSensors();
ObstacleReading readObstacleSensors();
float readGyroYawDeg();
bool localColorSuggestsGreen();
void handleCommand(const String& rawCommand);
String valueForKey(const String& line, const String& key, const String& fallback);
float floatForKey(const String& line, const String& key, float fallback);
long longForKey(const String& line, const String& key, long fallback);
bool boolForKey(const String& line, const String& key, bool fallback);
void copyTokenValue(const String& value, char* target, size_t targetSize);
bool tokenEquals(const char* value, const char* expected);
void refreshHeartbeat();
bool hasFreshLineAssist();
void updateControl(unsigned long nowMs);
void executeFollowLine(unsigned long nowMs);
void executeGreenManeuver(unsigned long nowMs);
void executeObstacleAvoidance(unsigned long nowMs);
void setMode(ControlMode nextMode, unsigned long nowMs);
void resetPid();
void applyMotorCommand(int leftPwm, int rightPwm);
void stopMotors();
void emitTelemetry(unsigned long nowMs);
const char* modeName(ControlMode mode);

void setup() {
  Serial.begin(SERIAL_BAUD);
  lineBuffer.reserve(160);

  pinMode(LEFT_PWM_PIN, OUTPUT);
  pinMode(LEFT_IN1_PIN, OUTPUT);
  pinMode(LEFT_IN2_PIN, OUTPUT);
  pinMode(RIGHT_PWM_PIN, OUTPUT);
  pinMode(RIGHT_IN1_PIN, OUTPUT);
  pinMode(RIGHT_IN2_PIN, OUTPUT);

  if (!CAMERA_ASSIST_ONLY_MODE) {
    for (int i = 0; i < LINE_SENSOR_COUNT; ++i) {
      pinMode(LINE_SENSOR_PINS[i], INPUT);
    }
  }
  if (FRONT_SENSOR_PIN >= 0) pinMode(FRONT_SENSOR_PIN, INPUT_PULLUP);
  if (FRONT_LEFT_SENSOR_PIN >= 0) pinMode(FRONT_LEFT_SENSOR_PIN, INPUT_PULLUP);
  if (FRONT_RIGHT_SENSOR_PIN >= 0) pinMode(FRONT_RIGHT_SENSOR_PIN, INPUT_PULLUP);

  stopMotors();
  refreshHeartbeat();
  setMode(MODE_SAFE_STOP, millis());
  Serial.println("READY FUSIONZERO");
}

void loop() {
  while (Serial.available() > 0) {
    char ch = (char)Serial.read();
    if (ch == '\n' || ch == '\r') {
      if (lineBuffer.length() > 0) {
        handleCommand(lineBuffer);
        lineBuffer = "";
      }
    } else if (lineBuffer.length() < 159) {
      lineBuffer += ch;
    }
  }

  unsigned long nowMs = millis();
  if ((nowMs - lastControlAtMs) >= CONTROL_PERIOD_MS) {
    lastControlAtMs = nowMs;
    updateControl(nowMs);
  }
  if ((nowMs - lastTelemetryAtMs) >= TELEMETRY_PERIOD_MS) {
    lastTelemetryAtMs = nowMs;
    emitTelemetry(nowMs);
  }
}

void handleCommand(const String& rawCommand) {
  String command = rawCommand;
  command.trim();
  if (command.length() == 0) {
    return;
  }

  if (command == "PING") {
    refreshHeartbeat();
    Serial.println("PONG");
    return;
  }

  if (command == "CMD ESTOP 0") {
    estopLatched = true;
    setMode(MODE_ESTOP, millis());
    stopMotors();
    Serial.println("ACK ESTOP");
    return;
  }

  if (command == "CMD RESET_ESTOP 0") {
    estopLatched = false;
    failsafeSerialLoss = false;
    watchdogEventSent = false;
    resetPid();
    refreshHeartbeat();
    setMode(MODE_SAFE_STOP, millis());
    Serial.println("ACK RESET_ESTOP");
    return;
  }

  if (estopLatched) {
    Serial.println("ERR estop_latched");
    return;
  }

  if (command.startsWith("CMD FORWARD ")) {
    long durationMs = command.substring(12).toInt();
    if (durationMs <= 0) {
      Serial.println("ERR invalid_duration");
      return;
    }
    manualForwardUntilMs = millis() + (unsigned long)durationMs;
    refreshHeartbeat();
    setMode(MODE_MANUAL_FORWARD, millis());
    Serial.print("ACK FORWARD ");
    Serial.println(durationMs);
    return;
  }

  if (command == "CMD STOP 0") {
    manualForwardUntilMs = 0;
    lineAssist.valid = false;
    lineAssist.found = false;
    greenAssist.active = false;
    obstacleAssist.active = false;
    strcpy(obstacleAssist.state, "CLEAR");
    failsafeSerialLoss = false;
    refreshHeartbeat();
    resetPid();
    stopMotors();
    setMode(MODE_SAFE_STOP, millis());
    Serial.println("ACK STOP");
    return;
  }

  if (command.startsWith("ASST LINE ")) {
    lineAssist.valid = true;
    lineAssist.found = boolForKey(command, "found", true);
    lineAssist.offsetNorm = clampFloat(floatForKey(command, "offset", 0.0f), -1.0f, 1.0f);
    lineAssist.angleDeg = floatForKey(command, "angle", 90.0f);
    lineAssist.confidence = clampFloat(floatForKey(command, "conf", 0.0f), 0.0f, 1.0f);
    lineAssist.gapFrames = (int)longForKey(command, "gap", 0);
    lineAssist.expiresAtMs = millis() + LINE_ASSIST_VALID_MS;
    refreshHeartbeat();
    Serial.println("ACK ASST LINE");
    return;
  }

  if (command.startsWith("ASST GREEN ")) {
    if (!boolForKey(command, "found", true)) {
      greenAssist.active = false;
      strcpy(greenAssist.instruction, "NO_GREEN");
      strcpy(greenAssist.side, "NONE");
      refreshHeartbeat();
      Serial.println("ACK ASST GREEN");
      return;
    }
    copyTokenValue(valueForKey(command, "instruction", "NO_GREEN"), greenAssist.instruction, sizeof(greenAssist.instruction));
    copyTokenValue(valueForKey(command, "side", "NONE"), greenAssist.side, sizeof(greenAssist.side));
    greenAssist.confidence = clampFloat(floatForKey(command, "conf", 0.0f), 0.0f, 1.0f);
    greenAssist.expiresAtMs = millis() + (unsigned long)max(0L, longForKey(command, "hold_ms", 900L));
    greenAssist.active = greenAssist.confidence >= 0.20f;
    if (greenAssist.active) {
      setMode(MODE_GREEN_MANEUVER, millis());
    }
    refreshHeartbeat();
    Serial.println("ACK ASST GREEN");
    return;
  }

  if (command.startsWith("ASST OBSTACLE ")) {
    copyTokenValue(valueForKey(command, "state", "CLEAR"), obstacleAssist.state, sizeof(obstacleAssist.state));
    obstacleAssist.confidence = clampFloat(floatForKey(command, "conf", 0.0f), 0.0f, 1.0f);
    obstacleAssist.expiresAtMs = millis() + (unsigned long)max(0L, longForKey(command, "hold_ms", 1200L));
    obstacleAssist.active = !tokenEquals(obstacleAssist.state, "CLEAR");
    if (obstacleAssist.active) {
      setMode(MODE_OBSTACLE_AVOID, millis());
    }
    refreshHeartbeat();
    Serial.println("ACK ASST OBSTACLE");
    return;
  }

  Serial.println("ERR unknown_command");
}

String valueForKey(const String& line, const String& key, const String& fallback) {
  String token = key + "=";
  int start = line.indexOf(token);
  if (start < 0) {
    return fallback;
  }
  start += token.length();
  int end = line.indexOf(' ', start);
  if (end < 0) {
    end = line.length();
  }
  String value = line.substring(start, end);
  value.trim();
  return value.length() > 0 ? value : fallback;
}

float floatForKey(const String& line, const String& key, float fallback) {
  return valueForKey(line, key, String(fallback, 3)).toFloat();
}

long longForKey(const String& line, const String& key, long fallback) {
  return valueForKey(line, key, String(fallback)).toInt();
}

bool boolForKey(const String& line, const String& key, bool fallback) {
  String value = valueForKey(line, key, fallback ? "1" : "0");
  value.toUpperCase();
  return value == "1" || value == "TRUE" || value == "YES" || value == "ON";
}

void copyTokenValue(const String& value, char* target, size_t targetSize) {
  if (target == NULL || targetSize == 0) {
    return;
  }
  value.toCharArray(target, targetSize);
  target[targetSize - 1] = '\0';
}

bool tokenEquals(const char* value, const char* expected) {
  if (value == NULL || expected == NULL) {
    return false;
  }
  return strcmp(value, expected) == 0;
}

void refreshHeartbeat() {
  lastHeartbeatAtMs = millis();
  watchdogEventSent = false;
  failsafeSerialLoss = false;
}

bool hasFreshLineAssist() {
  return lineAssist.valid && lineAssist.found && lineAssist.confidence >= 0.25f;
}

float fAbs(float value) {
  return value >= 0.0f ? value : -value;
}

float clampFloat(float value, float low, float high) {
  if (value < low) return low;
  if (value > high) return high;
  return value;
}

float normalizeLineSensor(int rawValue, int minValue, int maxValue) {
  if (maxValue <= minValue) {
    return 0.0f;
  }
  float normalized = float(rawValue - minValue) / float(maxValue - minValue);
  normalized = clampFloat(normalized, 0.0f, 1.0f);
  return LINE_BLACK_IS_LOW ? (1.0f - normalized) : normalized;
}

LineReading readLineSensors() {
  if (CAMERA_ASSIST_ONLY_MODE) {
    LineReading out = {false, 0.0f, 0.0f, 0};
    return out;
  }

  float weighted = 0.0f;
  float total = 0.0f;
  int activeCount = 0;

  for (int i = 0; i < LINE_SENSOR_COUNT; ++i) {
    int raw = analogRead(LINE_SENSOR_PINS[i]);
    float blackStrength = normalizeLineSensor(raw, LINE_SENSOR_CAL_MIN[i], LINE_SENSOR_CAL_MAX[i]);
    weighted += blackStrength * LINE_SENSOR_WEIGHTS[i];
    total += blackStrength;
    if (blackStrength >= LINE_ACTIVE_THRESHOLD) {
      activeCount += 1;
    }
  }

  LineReading out;
  out.found = total > 0.06f && activeCount > 0;
  out.error = 0.0f;
  out.confidence = clampFloat(total / (LINE_SENSOR_COUNT * 0.65f), 0.0f, 1.0f);
  out.activeCount = activeCount;
  if (out.found && total > 0.001f) {
    out.error = clampFloat(weighted / total, -1.0f, 1.0f);
  }
  return out;
}

ObstacleReading readObstacleSensors() {
  ObstacleReading out;
  out.frontBlocked = false;
  out.leftBlocked = false;
  out.rightBlocked = false;
  out.frontMm = 1200;
  out.leftMm = 1200;
  out.rightMm = 1200;

  if (FRONT_SENSOR_PIN >= 0) {
    bool blocked = digitalRead(FRONT_SENSOR_PIN) == (FRONT_SENSOR_ACTIVE_LOW ? LOW : HIGH);
    out.frontBlocked = blocked;
    out.frontMm = blocked ? 140 : 1200;
  }
  if (FRONT_LEFT_SENSOR_PIN >= 0) {
    bool blocked = digitalRead(FRONT_LEFT_SENSOR_PIN) == (FRONT_SENSOR_ACTIVE_LOW ? LOW : HIGH);
    out.leftBlocked = blocked;
    out.leftMm = blocked ? 180 : 1200;
  }
  if (FRONT_RIGHT_SENSOR_PIN >= 0) {
    bool blocked = digitalRead(FRONT_RIGHT_SENSOR_PIN) == (FRONT_SENSOR_ACTIVE_LOW ? LOW : HIGH);
    out.rightBlocked = blocked;
    out.rightMm = blocked ? 180 : 1200;
  }
  return out;
}

float readGyroYawDeg() {
  if (!GYRO_ENABLED) {
    return 0.0f;
  }
  return 0.0f;  // TODO: replace with real IMU integration.
}

bool localColorSuggestsGreen() {
  if (!LOCAL_COLOR_SENSOR_ENABLED) {
    return false;
  }
  return false;  // TODO: replace with real color sensor confirmation.
}

void updateControl(unsigned long nowMs) {
  if (lineAssist.valid && nowMs > lineAssist.expiresAtMs) {
    lineAssist.valid = false;
  }
  if (greenAssist.active && nowMs > greenAssist.expiresAtMs) {
    greenAssist.active = false;
  }
  if (obstacleAssist.active && nowMs > obstacleAssist.expiresAtMs) {
    obstacleAssist.active = false;
    strcpy(obstacleAssist.state, "CLEAR");
  }

  lastLine = readLineSensors();
  lastObstacle = readObstacleSensors();
  bool lineAssistReady = hasFreshLineAssist();

  bool serialHealthy = (nowMs - lastHeartbeatAtMs) <= HEARTBEAT_TIMEOUT_MS;
  if (!serialHealthy) {
    failsafeSerialLoss = true;
    if (!watchdogEventSent) {
      Serial.println("EVENT WATCHDOG_STOP");
      watchdogEventSent = true;
    }
  }

  if (failsafeSerialLoss && CAMERA_ASSIST_ONLY_MODE) {
    setMode(MODE_SAFE_STOP, nowMs);
    stopMotors();
    return;
  }

  if (estopLatched) {
    setMode(MODE_ESTOP, nowMs);
    stopMotors();
    return;
  }

  bool obstacleTriggered = lastObstacle.frontBlocked || obstacleAssist.active || tokenEquals(obstacleAssist.state, "TEST");
  if (obstacleTriggered) {
    setMode(MODE_OBSTACLE_AVOID, nowMs);
  }

  if (!obstacleTriggered && (greenAssist.active || localColorSuggestsGreen())) {
    setMode(MODE_GREEN_MANEUVER, nowMs);
  }

  if (currentMode == MODE_MANUAL_FORWARD) {
    if (failsafeSerialLoss || obstacleTriggered) {
      manualForwardUntilMs = 0;
      setMode(obstacleTriggered ? MODE_OBSTACLE_AVOID : MODE_SAFE_STOP, nowMs);
    } else if (nowMs >= manualForwardUntilMs) {
      manualForwardUntilMs = 0;
      setMode(MODE_SAFE_STOP, nowMs);
    } else {
      applyMotorCommand(speedCfg.straight, speedCfg.straight);
      return;
    }
  }

  if (failsafeSerialLoss && !lastLine.found && !lineAssistReady) {
    setMode(MODE_SAFE_STOP, nowMs);
    stopMotors();
    return;
  }

  switch (currentMode) {
    case MODE_GREEN_MANEUVER:
      executeGreenManeuver(nowMs);
      break;
    case MODE_OBSTACLE_AVOID:
      executeObstacleAvoidance(nowMs);
      break;
    case MODE_FOLLOW_LINE:
      executeFollowLine(nowMs);
      break;
    case MODE_ESTOP:
      stopMotors();
      break;
    case MODE_SAFE_STOP:
    default:
      if (lastLine.found || lineAssistReady) {
        setMode(MODE_FOLLOW_LINE, nowMs);
        executeFollowLine(nowMs);
      } else {
        stopMotors();
      }
      break;
  }
}

void executeFollowLine(unsigned long nowMs) {
  (void)nowMs;
  float fusedError = lastLine.error;
  float fusedConfidence = lastLine.confidence;
  bool lineAssistReady = hasFreshLineAssist();

  if (lineAssistReady) {
    float visionWeight = clampFloat(lineAssist.confidence * 0.35f, 0.0f, 0.35f);
    if (lastLine.found) {
      fusedError = ((1.0f - visionWeight) * lastLine.error) + (visionWeight * lineAssist.offsetNorm);
    } else if (lineAssist.confidence >= 0.25f) {
      fusedError = lineAssist.offsetNorm;
      fusedConfidence = lineAssist.confidence;
    }
  }

  if (!lastLine.found && !lineAssistReady) {
    stopMotors();
    return;
  }

  float dt = CONTROL_PERIOD_MS / 1000.0f;
  float safeDt = dt < 0.001f ? 0.001f : dt;
  pidState.filteredError += pidCfg.smoothingAlpha * (fusedError - pidState.filteredError);
  float derivative = (pidState.filteredError - pidState.lastFilteredError) / safeDt;
  derivative = clampFloat(derivative, -pidCfg.derivativeLimit, pidCfg.derivativeLimit);

  float tentativeIntegral = clampFloat(
    pidState.integral + (pidState.filteredError * dt),
    -pidCfg.integralLimit,
    pidCfg.integralLimit
  );
  float headingTarget = 0.0f;
  if (lineAssistReady) {
    headingTarget = clampFloat((lineAssist.angleDeg - 90.0f) / 90.0f, -1.0f, 1.0f) * 18.0f;
  }
  float headingCorrection = GYRO_ENABLED ? ((headingTarget - readGyroYawDeg()) * pidCfg.headingKp) : 0.0f;
  float unsaturated = (
    (pidCfg.kp * pidState.filteredError) +
    (pidCfg.ki * tentativeIntegral) +
    (pidCfg.kd * derivative) +
    headingCorrection
  );
  float saturated = clampFloat(unsaturated, -pidCfg.maxTurn, pidCfg.maxTurn);
  if ((saturated == unsaturated) || ((saturated > 0.0f) && (pidState.filteredError < 0.0f)) || ((saturated < 0.0f) && (pidState.filteredError > 0.0f))) {
    pidState.integral = tentativeIntegral;
  }

  int baseSpeed = speedCfg.straight;
  float severity = fAbs(fusedError);
  if (severity > 0.55f) {
    baseSpeed = speedCfg.curve;
  } else if (severity > 0.25f) {
    baseSpeed = speedCfg.medium;
  }
  if (fusedConfidence < 0.35f || failsafeSerialLoss) {
    baseSpeed = speedCfg.cautious;
  }

  pidState.derivative = derivative;
  pidState.output = saturated;
  pidState.lastFilteredError = pidState.filteredError;

  int left = (int)(baseSpeed - saturated);
  int right = (int)(baseSpeed + saturated);
  applyMotorCommand(left, right);
  currentMode = MODE_FOLLOW_LINE;
}

void executeGreenManeuver(unsigned long nowMs) {
  unsigned long elapsed = nowMs - maneuverStartedAtMs;

  if (!greenAssist.active) {
    setMode(MODE_FOLLOW_LINE, nowMs);
    return;
  }

  if (tokenEquals(greenAssist.instruction, "VERDE_MEIA_VOLTA")) {
    if (elapsed < 780) {
      applyMotorCommand(-speedCfg.turn, speedCfg.turn);
      return;
    }
  } else if (tokenEquals(greenAssist.instruction, "VERDE_ANTES")) {
    if (elapsed < 430) {
      applyMotorCommand(-speedCfg.turn, speedCfg.turn);
      return;
    }
    if (elapsed < 850) {
      applyMotorCommand(speedCfg.cautious, speedCfg.cautious);
      return;
    }
  } else if (tokenEquals(greenAssist.instruction, "VERDE_DEPOIS")) {
    if (elapsed < 430) {
      applyMotorCommand(speedCfg.turn, -speedCfg.turn);
      return;
    }
    if (elapsed < 850) {
      applyMotorCommand(speedCfg.cautious, speedCfg.cautious);
      return;
    }
  } else {
    greenAssist.active = false;
  }

  greenAssist.active = false;
  setMode(MODE_FOLLOW_LINE, nowMs);
}

void executeObstacleAvoidance(unsigned long nowMs) {
  unsigned long elapsed = nowMs - obstacleStartedAtMs;
  bool preferLeft = lastObstacle.rightBlocked && !lastObstacle.leftBlocked;
  bool preferRight = lastObstacle.leftBlocked && !lastObstacle.rightBlocked;
  int turnDir = preferLeft ? -1 : 1;
  if (preferRight) {
    turnDir = 1;
  }

  if (tokenEquals(obstacleAssist.state, "CLEAR") && !lastObstacle.frontBlocked && elapsed > 200) {
    obstacleAssist.active = false;
    setMode(MODE_FOLLOW_LINE, nowMs);
    return;
  }

  if (elapsed < 180) {
    applyMotorCommand(-speedCfg.reverse, -speedCfg.reverse);
    return;
  }
  if (elapsed < 620) {
    applyMotorCommand(-turnDir * speedCfg.turn, turnDir * speedCfg.turn);
    return;
  }
  if (elapsed < 1220) {
    applyMotorCommand(speedCfg.cautious, speedCfg.cautious);
    return;
  }
  if (elapsed < 1580) {
    applyMotorCommand(turnDir * speedCfg.turn, -turnDir * speedCfg.turn);
    return;
  }

  obstacleAssist.active = false;
  strcpy(obstacleAssist.state, "CLEAR");
  setMode(MODE_FOLLOW_LINE, nowMs);
}
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

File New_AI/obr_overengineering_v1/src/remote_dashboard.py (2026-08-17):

from __future__ import annotations

import itertools
import json
import socket
import threading
import time
from collections import deque
from dataclasses import asdict, dataclass, field
from pathlib import Path
from typing import Any, Callable, Mapping

import numpy as np

try:
    import cv2
except Exception:  # pragma: no cover
    cv2 = None

if __package__ in (None, ""):
    SRC_ROOT = Path(__file__).resolve().parent
    import sys

    if str(SRC_ROOT) not in sys.path:
        sys.path.insert(0, str(SRC_ROOT))

    from core.event_bus import (  # type: ignore
        EventBus,
        EventBusError,
        EventBusFullError,
        EventTopic,
        FrameEvent,
        HealthEvent,
        LogEvent,
        PathEvent,
        PoseEvent,
        StateSnapshotEvent,
        StateTransitionEvent,
        Subscription,
        UICommandEvent,
        VisionDetectionEvent,
    )
else:
    from .core.event_bus import (
        EventBus,
        EventBusError,
        EventBusFullError,
        EventTopic,
        FrameEvent,
        HealthEvent,
        LogEvent,
        PathEvent,
        PoseEvent,
        StateSnapshotEvent,
        StateTransitionEvent,
        Subscription,
        UICommandEvent,
        VisionDetectionEvent,
    )


CONTROL_TOPIC = "__remote_control__"


@dataclass(slots=True)
class ControlMessage:
    timestamp: float = field(default_factory=time.time)
    kind: str = ""
    detail: dict[str, Any] = field(default_factory=dict)
    session_id: int = 0


EVENT_CLASS_BY_NAME: dict[str, type[Any]] = {
    "ControlMessage": ControlMessage,
    "FrameEvent": FrameEvent,
    "HealthEvent": HealthEvent,
    "LogEvent": LogEvent,
    "PathEvent": PathEvent,
    "PoseEvent": PoseEvent,
    "StateSnapshotEvent": StateSnapshotEvent,
    "StateTransitionEvent": StateTransitionEvent,
    "UICommandEvent": UICommandEvent,
    "VisionDetectionEvent": VisionDetectionEvent,
}

FORWARDED_TOPICS: tuple[EventTopic, ...] = (
    EventTopic.VISION_RAW_FRAME,
    EventTopic.VISION_PROCESSED_FRAME,
    EventTopic.VISION_DETECTIONS,
    EventTopic.FSM_STATE,
    EventTopic.FSM_TRANSITION,
    EventTopic.SYSTEM_HEALTH,
    EventTopic.SYSTEM_LOG,
    EventTopic.NAV_PATH,
)


def _read_exact(sock: socket.socket, size: int) -> bytes:
    chunks: list[bytes] = []
    remaining = int(size)
    while remaining > 0:
        chunk = sock.recv(remaining)
        if not chunk:
            raise ConnectionError("socket closed")
        chunks.append(chunk)
        remaining -= len(chunk)
    return b"".join(chunks)


def _encode_frame_payload(event: FrameEvent, jpeg_quality: int) -> tuple[dict[str, Any], bytes]:
    encoding = str(event.encoding or "bgr8").strip().lower()
    payload = bytes(event.data)
    fields = {
        "timestamp": float(event.timestamp),
        "frame_id": int(event.frame_id),
        "width": int(event.width),
        "height": int(event.height),
        "encoding": encoding,
    }
    if encoding in {"jpeg", "jpg"}:
        fields["encoding"] = "jpeg"
        return fields, payload

    if cv2 is None or event.width <= 0 or event.height <= 0:
        return fields, payload

    raw = np.frombuffer(event.data, dtype=np.uint8)
    expected = int(event.width) * int(event.height) * 3
    if raw.size < expected:
        return fields, payload

    frame = raw[:expected].reshape((int(event.height), int(event.width), 3))
    if encoding.startswith("rgb"):
        frame = frame[:, :, ::-1]

    ok, encoded = cv2.imencode(".jpg", frame, [int(cv2.IMWRITE_JPEG_QUALITY), int(jpeg_quality)])
    if not ok:
        return fields, payload

    fields["encoding"] = "jpeg"
    return fields, encoded.tobytes()


def pack_event_message(topic: str, event: object, *, jpeg_quality: int = 70) -> bytes:
    if isinstance(event, FrameEvent):
        fields, payload = _encode_frame_payload(event, jpeg_quality)
    else:
        fields = asdict(event)
        payload = b""

    header = {
        "topic": str(topic),
        "event_type": type(event).__name__,
        "payload_length": int(len(payload)),
        "fields": fields,
    }
    header_bytes = json.dumps(header, separators=(",", ":"), ensure_ascii=True).encode("utf-8")
    return len(header_bytes).to_bytes(4, byteorder="big", signed=False) + header_bytes + payload
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

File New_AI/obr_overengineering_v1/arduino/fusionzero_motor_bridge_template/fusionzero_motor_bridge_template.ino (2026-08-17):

/*
  FusionZero serial motor bridge template

  Protocol:
    PING
    CMD FORWARD <duration_ms>
    CMD STOP 0
    CMD ESTOP 0
    CMD RESET_ESTOP 0

  Responses:
    READY FUSIONZERO
    PONG
    ACK FORWARD <duration_ms>
    ACK STOP
    ACK ESTOP
    ACK RESET_ESTOP
    ERR <reason>
    EVENT WATCHDOG_STOP

  Safety:
    - Raspberry sends heartbeat PINGs while idle or while a motion is active.
    - If the heartbeat disappears, this sketch stops both motors automatically.
    - CMD ESTOP latches an emergency stop until CMD RESET_ESTOP 0 is received.

  Edit the pin mapping below to match the motor driver actually used on the robot.
*/

const long SERIAL_BAUD = 115200;
const unsigned long HEARTBEAT_TIMEOUT_MS = 1500;

const int LEFT_PWM_PIN = 5;
const int LEFT_IN1_PIN = 7;
const int LEFT_IN2_PIN = 8;
const int RIGHT_PWM_PIN = 6;
const int RIGHT_IN1_PIN = 9;
const int RIGHT_IN2_PIN = 10;

const int DEFAULT_SPEED = 170;

String lineBuffer;
unsigned long forwardUntilMs = 0;
unsigned long watchdogDeadlineMs = 0;
bool estopLatched = false;
bool watchdogStopAnnounced = false;

void setup() {
  Serial.begin(SERIAL_BAUD);
  lineBuffer.reserve(64);

  pinMode(LEFT_PWM_PIN, OUTPUT);
  pinMode(LEFT_IN1_PIN, OUTPUT);
  pinMode(LEFT_IN2_PIN, OUTPUT);
  pinMode(RIGHT_PWM_PIN, OUTPUT);
  pinMode(RIGHT_IN1_PIN, OUTPUT);
  pinMode(RIGHT_IN2_PIN, OUTPUT);

  stopMotors();
  refreshWatchdog();
  Serial.println("READY FUSIONZERO");
}

void loop() {
  while (Serial.available() > 0) {
    char ch = (char)Serial.read();
    if (ch == '\n' || ch == '\r') {
      if (lineBuffer.length() > 0) {
        handleCommand(lineBuffer);
        lineBuffer = "";
      }
    } else {
      lineBuffer += ch;
    }
  }

  if (!estopLatched && forwardUntilMs > 0 && millis() >= forwardUntilMs) {
    stopMotors();
    forwardUntilMs = 0;
    Serial.println("ACK STOP");
  }

  if (!estopLatched && watchdogDeadlineMs > 0 && millis() >= watchdogDeadlineMs) {
    stopMotors();
    forwardUntilMs = 0;
    watchdogDeadlineMs = 0;
    if (!watchdogStopAnnounced) {
      watchdogStopAnnounced = true;
      Serial.println("EVENT WATCHDOG_STOP");
    }
  }
}

void handleCommand(const String& rawCommand) {
  String command = rawCommand;
  command.trim();

  if (command == "PING") {
    refreshWatchdog();
    Serial.println("PONG");
    return;
  }

  if (command == "CMD ESTOP 0") {
    stopMotors();
    forwardUntilMs = 0;
    estopLatched = true;
    watchdogDeadlineMs = 0;
    watchdogStopAnnounced = false;
    Serial.println("ACK ESTOP");
    return;
  }

  if (command == "CMD RESET_ESTOP 0") {
    estopLatched = false;
    refreshWatchdog();
    Serial.println("ACK RESET_ESTOP");
    return;
  }

  if (estopLatched) {
    Serial.println("ERR estop_latched");
    return;
  }

  if (command.startsWith("CMD FORWARD ")) {
    long durationMs = command.substring(12).toInt();
    if (durationMs <= 0) {
      Serial.println("ERR invalid_duration");
      return;
    }
    driveForward(DEFAULT_SPEED);
    forwardUntilMs = millis() + (unsigned long)durationMs;
    refreshWatchdog();
    Serial.print("ACK FORWARD ");
    Serial.println(durationMs);
    return;
  }

  if (command == "CMD STOP 0") {
    stopMotors();
    forwardUntilMs = 0;
    refreshWatchdog();
    Serial.println("ACK STOP");
    return;
  }

  Serial.println("ERR unknown_command");
}

void refreshWatchdog() {
  watchdogDeadlineMs = millis() + HEARTBEAT_TIMEOUT_MS;
  watchdogStopAnnounced = false;
}

void driveForward(int pwm) {
  digitalWrite(LEFT_IN1_PIN, HIGH);
  digitalWrite(LEFT_IN2_PIN, LOW);
  digitalWrite(RIGHT_IN1_PIN, HIGH);
  digitalWrite(RIGHT_IN2_PIN, LOW);
  analogWrite(LEFT_PWM_PIN, pwm);
  analogWrite(RIGHT_PWM_PIN, pwm);
}

void stopMotors() {
  analogWrite(LEFT_PWM_PIN, 0);
  analogWrite(RIGHT_PWM_PIN, 0);
  digitalWrite(LEFT_IN1_PIN, LOW);
  digitalWrite(LEFT_IN2_PIN, LOW);
  digitalWrite(RIGHT_IN1_PIN, LOW);
  digitalWrite(RIGHT_IN2_PIN, LOW);
}

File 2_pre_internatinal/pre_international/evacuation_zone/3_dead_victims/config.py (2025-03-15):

WIDTH, HEIGHT, FLIP = 320, 240, False
SCREEN_WIDTH, SCREEN_HEIGHT = 128, 64
X11 = True

touch_pins  = [6, 5, 22, 26]
x_shut_pins = [23, 24]

stop_angles = [89, 88, 89, 88]
servo_pins = [14, 13, 12, 10]
claw_pin = 9

# ------------------------------------------

status_messages = []

victim_count = 2
evacuation_speed = 35
approach_distance = 18

def update_log(data: list[str], coloumn_widths: list[int], separator: str = "|") -> str:
    formatted_cells = [f"{cell:^{width}}" for cell, width in zip(data, coloumn_widths)]
    return f" {separator} ".join(formatted_cells)

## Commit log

2024-12-02 initial tests; - touch sensors don't work because of wiring? maybe a skill issue - servo's work fine - lasers work fine - using a python virtual environment to keep library versions clean
    [pyvenv.cfg]
2024-12-02 fixed the touch sensor tests - confusion with BCM and BOARD - switched from pull down to pull up
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2024-12-04 calibration generates equation: - no distinction between positive and negative - cannot display graphs
2024-12-05 Added line following code along with folders to hold the seperate versions, added Camera testing code I2C testing folder, matched naming conventions and improved servo testing code
2024-12-05 Finished servo calibration - linear ramp - equal servo speeds
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2024-12-06 Changed U-Turn detection to increase reliability (instead of seeing left or right on U-Turns). Added stopping motors during Line-following functionality using cv2.waitKey for inputs.
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2024-12-14 fixed some more motor calibration added more steps to validating the exit
    [config.py, main.py]
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2024-12-15 Fixed led code from GPIO.OUTPUT to OUT. Added led version of line following. Although, my attempts to fix the black line following on the difficult multiple 90 degree turos was not successful. Perhap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
    [Main.py, config.py]
2024-12-15 Using adafruit library for readin ads7830 with front right and middle right values stil coupling and affecting nearby/other analog inputs
2024-12-16 Fixed invalidate contour determining by ensuring that it pcisk the contour most similar to the previous frame.
    [Main.py, config.py]
2024-12-17 Fixed green validation, by changing check point based on gradient being negative or positive as it multiplies negative vectors causing the check points to check below green instead of above green. Al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
    [Main.py, config.py]
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2024-12-18 Attempted to recognize gaps for extended amount of time to confirm an evacuation zone entry. However silver appears similar to black. Thus for now we must skip this.
    [Main.py, config.py]
2024-12-18 Fixed camera not displaying. Now use cv2 commadns inside of XMing window to control the robot. Including WASD for motors, Space to stop, L for led, and q to exit.
2024-12-18 standardized console output, fixed spelling
    [main.py]
2024-12-18 Improved line following and green turns. However, double green detection has an issue with display or corrupting the display image. Framerate is also curcial to line following and green turn consiste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
    [Main.py, config.py]
2024-12-19 with new camera frame, more development. Added spectralhighlight, routing
2024-12-22 adjusted logic and flow, much easier to work with now
2024-12-27 fixed logic flow
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2024-12-28 fixing print -> more bugs
    [config.py, main.py]
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2024-12-31 printing + logic fixed
    [config.py, main.py]
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2025-01-07 Moved cam line following sub folders into the right folder, created simple black line following code with auto calibration. Updated colour sensors testing code with better delays.
2025-01-08 Improved black line following, using the front middle colour sensor and also improving motors, reducing the bias with motor calibration.
2025-01-09 Added Obstacle avoidance, laser sensor data, and touch sensor readings. Changed some function names.
    [main.py]
2025-01-12 Added config variable to choose whether to use low transformed image or the normal image from the camera for HSV mask.
2025-01-14 fixing file / folder structure
    [config.py, main.py]
2025-01-15 some more fixing but idk what i'm doing
    [main.py]
2025-01-15 calibration now fixed, manual overwrite
2025-01-15 Fixed callibration in version 5_inverse of colour line following.
    [main.py]
2025-02-17 removed virtual enviornment
    [pyvenv.cfg]
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2025-02-18 updated intersection w/ PID correctly added?
2025-02-19 some print fixes
2025-02-23 general green complete TODO: fix |- -| intersections, moving forwards until sensor sees black
    [main.py]
2025-02-26 speed increased - integral unbound to 10,000 - fixed intersection timings - added blue validation for claw - fixed |- -| alignment
    [config.py]
2025-03-02 gap_handling complete with sensor fusion -> camera now takes control
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2025-03-09 Fixed led function calling names
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2025-03-09 Added camera line following
    Camera line following function added.
    Updated PID function:
    1. Update gyro values in separate if statement
    2. Check for ramp, acute or evac exit for cam line following
    3. Else: turn off led and do normal line following
    Speeds and Kp values should be tuned further.
    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
2025-03-10 Updating with technical documents
    Updating in prep for Japan and Singapore
    [2 x 18650 Battery Holder.stp, BNOO8X Frame.step, Back Base.step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]
2025-03-10 updated from kP based line follow -> kI based line follow, kP, kD as overshoot correction
    [config.py, main.py]
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2025-03-15 calibration issues D:
2025-03-16 swapped back wheels
2025-03-17 fixing print statements and QOL
2025-03-18 camera resolution and output fix - using raw modifier to determine sensor format and output - using main modifier to determine output to use
    [config.py]
2025-03-19 victim detection testing - changed dead from RGB to HSV -> removed noise from background
    TODO: Find a way to sharpen ALL edges OR detect part of a contour that is circular
    [config.py]
2025-03-20 - victim count into file - fixed evacuation_speed - fixed print statements for debugging - fixed presence check - fixed grab sequence timings - added HSV filtering for triangles - added laser check f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
    [config.py, main.py]
2025-03-21 Improved lien following for Frederick triple green, added Aidan's motor values, removed acute handling as that was confusing the fork situations
2025-03-21 fixed more evacuation_zone things - fixed finding evac lines - added debugging for presence check - changed triangle alignemnet sequence to allow for side-on approaches - fixed readibility for dead-v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
2025-03-21 Lining up to evac. Basic evac exit. Need to fix camera line following as it doesn't work (Need to re init camera settings).
    [config.py]
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2025-03-25 green, obstacle, flow, fixes
    [config.py, main.py]
2025-03-26 inital idea, with a rocker switch program that runs on startup, allowing for starting and killing the competition_main.py which auto starts with line
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2025-03-29 calibrated presence check trying new exit values more red changes updated obstacle forced side or random
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2025-04-15 Completed green and black with new classes. Need to calibrate motors, calibrate green double turn times, do more running testing on green and black.
2025-04-24 Improved double green detection. Should first test silver dection. Then begin testing slanted, and speed bumps, incoporating the gyro.
2025-04-25 small adjustments to code.: green hold duration, double green turn duration.
    Further improvement to line following + green could be looking at hold green mechanism, and also not following the line if the contour is 180 or 0 degrees as in its touching the bottom for the reference point. Silver line could be viable with current setup as silver is slightly brighter in places compared to white however will probably still need colour sensors. General QoL imrovements could be threading to increase framerate although with X11 and without X11 doesn't rlly make a difference in performance. Could attempt threading with silver line ai detection if colour sensors do not work reliably.
2025-04-26 Fixed code structure. Beggining to add obstacle.
    [main.py]
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2025-05-01 changing folder structure
    [2 x 18650 Battery Holder.stp, BNOO8X Frame.step, Back Base.step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]
2025-05-03 Added functions from clean code into line.py (robot state + new functions). Detecting Ramps and Tilts now works. Made code for display images in seperate thread to decrease proccessing times
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2025-05-08 fixed the gap problem. need to ocnsider using robot state triggers/adding them back. could increase base speed after decrease servo voltage. Need to fix double green detection b y if len(green_contou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
2025-05-16 uncommented colour sensors, and gyro change follow line to follow function, add self. to image and display image, added lightest area for black masks, fixed timing with red and silver detetion for ca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
    [main.py]
2025-05-17 fixed line follow on tilted boards, fixed green on tilted boards except the angled double green that is recognized as uphill instead of tilted. obstacle doesnt work rn because rununtil does not exist.
2025-05-17 fixed green turns. more testing with line follow to ensure it works on normal boards. (mostly a test with difficult tiles and tilted difficult tiles were done but could test a greater variety of tile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
2025-05-20 Added ability to record. need to improve with proper timings, higher quality if possible, constantly recording and caputring images or just continuing capture during while loops or timed things in wh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
    [main.py]
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2025-05-21 added capture array into motors for continous videocapture, however may need to put video capture in seperate thread in order to keep delays accurate.
2025-05-22 attempted to use the mask instead of contours for more points to work with when finding angles. one of the wheg tires fell off. need to improve lighting or add a mask for the corners of the screen
2025-05-22 updated EvacState updated locate function to correctly turn based on error switched from wall_follow to random for now added alignment and grab
    updated control loop for evac
    added spaces to claw class
    calibrated motors
    added testing folder
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2025-05-25 added filtering based on x coodinate for live updated alignment to be fully laser based -> does not work for different sized victims added evacuation.base_speed added forced warmup and first inference
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2025-05-27 improved double green. improved obstacle. may need to increase speed and also add a stuck finder if gyro says low change in accelreation or waht not if stuck on a rare double speedbump + speedbump.
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2025-05-28 fixed claw.read() to take averages as well as account for variation in values
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2025-05-29 added camera gracefully exiting updated approach_distances for live and dead increased live threshold fixed analyse logic to support live, dead, green, red based on victims saved and currently held u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
    [main.py]
2025-05-30 added more configs to evac_zone lowered live threshold added try except block directly to TPU updated red thresholds for lower saturation changed random speeds counting how many empty slots in the cl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
2025-05-31 Calibrated old obstacle avoidance without testing downhill (kept new obstacle avoidance commented out)
    [main.py]
2025-05-31 updated for obstacle avoidance for uphill. Removed motor.pause() for obstacle avoidance. Removed commented new (now previous) obstacle avoidance.
2025-05-31 added hough_circle +threshold dead added threshold dead tried try except block for AI updated empty_count calculation normalised debug lengths reduced maximum height on camera increased timing budget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
2025-05-31 added source validation for classic live and hough dead fixed cropping issues and coordinate system with last_x added back try except block for claw.read
2025-06-01 Added blue silver detection, fixed hsv mask testing with perspective transform, changed led on off to just on. Updated blue threshold. showing blue contours. updated double green turns. more forwards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
2025-06-04 udpated reading from heavy sensors to be instantaneous: all sensors now read in a seperate thread in the background
2025-06-04 fixed all parallism for sensor readings required for evac_state
    [main.py]
2025-06-05 removed dependency on line follow speed in case we want to actually change line follow speed adn that ruins all other values.
2025-06-06 Reduced the hieght at which camera reads when it follors line uphill to avoid following shadows
2025-06-06 Added timing for calcualte angle specifically as well. figured out that clacualte abgle was taking a long time. may consider ways to optimize camera capturing in seperate thread and optimizing calcul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
2025-06-08 fix down hill obstacle, especially into a double green. improved downhill turns such that it works if its a striaght into it (but wierd tiles like 270 degree sharp turns or the special spiderweb tile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
    [main.py]
2025-06-20 downhill silver now working. however downhill is being ruined by tryign to get the s turn to work downhill so will need to use front camera and other things to get it to work.
2025-06-20 updated main.py to match the correct version
    [main.py]
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2025-06-29 fixed stuff for final merge
    [main.py]
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2025-07-02 fixes to laser, blcoking
    [main.py]
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2025-07-04 cleaned up silver detection, need more testing fake silvers (uphills and speedbumps). Could attempt to use gyro later
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2025-07-05 fixed silver, still need to look into turns downhill with speedbumpl
    [main.py]
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2025-07-07 added random seeding added extra debug info fixed live victim identification updated random spinning so it's not that random updated vairable names
    [main.py]
2025-07-07 fixed silver line detection added exit added triangles added wall follow added grabbing direction fail thing
    [main.py]
2025-07-08 silver updated with robot_state variable for easy switching, updated and fixed gap by decreasing camera back sight, and updated amount of forwards
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2025-07-11 added captre script into tests in 0_international/ in order to have updated camera settings befure capputring images for silver. updated closing camera etc in main and caputre script
2025-07-11 Add quantized silver detector model
    Added the quantized PyTorch model for silver line detection on Raspberry Pi 4. This model will be used for inference in the silver line detection pipeline.
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2025-07-16 added autostart script added saving video screen to main updated sensor pins
2025-09-26 realised that the issue with green is the led's so if it conitnues we can debug that next time
2025-09-27 hopefully fixed seeing green late but also could just be because of changing the wheels and making them less grippy at the back. may go back to just less grippy overall, so it has a consistent rotati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
2025-10-04 git ignore new saved frames in sessions.
    main: added new save frame stuff, removed old video proccessing
    line_follower:
    increase pid, decrease min black area, added seeperate turn color customization variable, added new black mask setup specific to the led placements and the dark corner shadows, fixed some variable if statmeents and naming, added a debug clear while the program starts running t avoid the spam at the start of hte run, updated green turn to better match decreased friction on tires. decrease check size of blakck for green turns, green mask ranges and erode cahnges, removed printing green contour area, remved unnecessary uncommented code for gaps, ,extra erode for gaps, increas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
    [main.py]
2025-10-09 fixed evac directions for turning, changed speeds and changed to blind dead victim grabbing in case the ir sensors fail for dead victims. also updated obstacle and functions that rely on colour value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
    [main.py]
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2026-08-17 chore: upload FusionZero project snapshot
    [metadata.csv]
